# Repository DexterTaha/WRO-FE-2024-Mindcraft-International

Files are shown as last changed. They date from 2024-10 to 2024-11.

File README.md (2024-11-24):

MINDCRAFT WRO Future Engineers team
====

<p align="center">
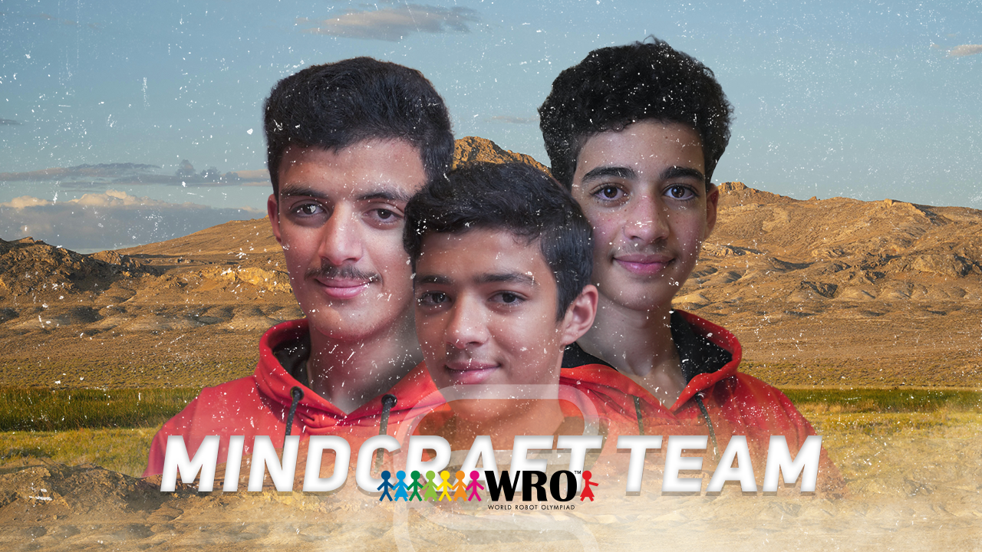
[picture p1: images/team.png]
banner
  
</p>

This repository provides information and knowledge regarding the ongoing progress, evolution, and development of our self-driving robot vehicle, which was created and coded by us, [Salmane Derdeb](https://github.com/salmane-derdeb),  [Taha TAIDI LAAMIRI](https://github.com/DexterTaha) and [Mortada TAIDI LAAMIRI](https://github.com/taidimortada) as participants in the Future Engineers 2024 division of the World Robot Olympiad (WRO).

## World Robot Olympiad (WRO)
<p align="center">
  
</p>

The World Robot Olympiad (WRO) is a prestigious international robotics competition that ignites the imaginations of students worldwide. It challenges participants to showcase their creativity, problem-solving skills, and technical prowess in designing and programming robots for a variety of tasks and challenges.

One of the most dynamic categories within WRO is the Future Engineers category. Here, participants are tasked with developing innovative solutions to real-world problems using robotics and automation. This category serves as a breeding ground for future innovators, encouraging students to think critically and creatively, laying the groundwork for a new generation of engineers and technologists.

This year, the Future Engineers category presents an exciting challenge: creating a self-driving car. This challenge pushes participants to explore the cutting edge of robotics, adding layers of complexity and innovation to an already thrilling competition.

[Watch the challenge explanation video](https://www.youtube.com/watch?v=_J15lf6uhwo&t=2s)

## Content

- `Models`: Contains files for models used by 3D printers, laser cutting machines, and CNC machines to produce the vehicle elements. If not needed, this directory can be removed.
- `docs`: Contains files for models used by 3D printers, laser cutting machines, and CNC machines to produce the vehicle elements. If not needed, this directory can be removed.
- `images`: Contains files for models used by 3D printers, laser cutting machines, and CNC machines to produce the vehicle elements. If not needed, this directory can be removed.
- `other`: Contains additional files that can help understand how to prepare the vehicle for the competition, such as documentation on connecting to a SBC/SBM, uploading files, datasets, hardware specifications, and communication protocols descriptions. If not needed, this directory can be removed.
- `schemes ( source code )`: Contains one or several schematic diagrams (JPEG, PNG, or PDF) illustrating all electromechanical components used in the vehicle, including electronic components and motors, and how they connect to each other.
- `src`: Contains the control software code for all components programmed to participate in the competition.
- `t-photos`: Contains 2 photos of the team, including an official one and a funny photo with all team members.
- `v-photos`: Contains 6 photos of the vehicle, showcasing it from every side as well as from the top and bottom.
- `videos`: Contains a `video.md` file with a link to a video demonstrating the vehicle's driving capabilities.

# WRO Future Engineers Competition

| **1.Mobility Management**             |
|:---------------------------------------|
| Mobility management discussion should cover how the vehicle movements are managed. What motors are selected, how they are selected and implemented. A brief discussion regarding the vehicle chassis design /selection can be provided as well as the mounting of all components to the vehicle chassis/structure. The discussion may include engineering principles such as speed, torque, power etc. usage. Building or assembly instructions can be provided together with 3D CAD files to 3D print parts.|
| [Robot Parts & Design](https://github.com/DexterTaha/WRO-FE-2024-Mindcraft-International/tree/2bbf1b3f514550d7e91d4fa6e24702a49f4da584/Models)      |
| [Power System](https://github.com/DexterTaha/WRO-FE-2024-Mindcraft-International/tree/ba104a2bcaaa4348022537fc64ced3bace19f17f/other/Power%20System) |
| [Sensing Units](https://github.com/DexterTaha/WRO-FE-2024-Mindcraft-International/tree/ba104a2bcaaa4348022537fc64ced3bace19f17f/other/Sensing%20Units) |
| [Steering System](https://github.com/DexterTaha/WRO-FE-2024-Mindcraft-International/tree/ba104a2bcaaa4348022537fc64ced3bace19f17f/other/Steering%20System) |

---

| **2.Power and Sense Management**        |
|:---------------------------------------|
|Power and Sense management discussion should cover the power source for the vehicle as well as the sensors required to provide the vehicle with information to negotiate the different challenges. The discussion can include the reasons for selecting various sensors and how they are being used on the vehicle together with power consumption. The discussion could include a wiring diagram with BOM for the vehicle that includes all aspects of professional wiring diagrams.|
| [Bill of Materials (BOM)](https://github.com/DexterTaha/WRO-FE-2024-Mindcraft-International/tree/2bbf1b3f514550d7e91d4fa6e24702a49f4da584/other/BOM(Bill%20of%20Materials))            |
| [Schematics](https://github.com/DexterTaha/WRO-FE-2024-Mindcraft-International/tree/2bbf1b3f514550d7e91d4fa6e24702a49f4da584/schemes)                   |

---

| **3.Obstacle Management**               |
|:---------------------------------------|
|Obstacle management discussion should include the strategy for the vehicle to negotiate the obstacle course for all the challenges. This could include flow diagrams, pseudo code and source code with detailed comments.|
| [Strategy](https://github.com/DexterTaha/WRO-FE-2024-Mindcraft-International/tree/2bbf1b3f514550d7e91d4fa6e24702a49f4da584/other/Strategy) |
| [Arduino Functions](https://github.com/DexterTaha/WRO-FE-2024-Mindcraft-International/tree/2bbf1b3f514550d7e91d4fa6e24702a49f4da584/src%20(%20source%20code%20)/Arduino%20Functions) |
| [Open challenge](https://github.com/DexterTaha/WRO-FE-2024-Mindcraft-International/tree/2bbf1b3f514550d7e91d4fa6e24702a49f4da584/src%20(%20source%20code%20)/Open%20Challenge) |
| [Dashboard Visualisation](https://github.com/DexterTaha/WRO-FE-2024-Mindcraft-International/tree/2bbf1b3f514550d7e91d4fa6e24702a49f4da584/src%20(%20source%20code%20)/Dashboard)|
| [Map randomizer & score calculator](https://dextertaha.github.io/WRO-FE-2024-Mindcraft-International/)|

---

| **4.Pictures – Team and Vehicle**       |
|:---------------------------------------|
| Pictures of the team and robot must be provided. The pictures of the robot must cover all sides of the robot, must be clear, in focus and show aspects of the mobility, power and sense, and obstacle management. Reference in the discussion sections 1, 2 and 3 can be made to these pictures. Team photo is necessary for judges to relate and identify the team during the local and international competitions. |
| [Vehicle Photos](https://github.com/DexterTaha/WRO-FE-2024-Mindcraft-International/tree/2bbf1b3f514550d7e91d4fa6e24702a49f4da584/v-photos)           |
| [Team Members & Pictures](https://github.com/DexterTaha/WRO-FE-2024-Mindcraft-International/tree/2bbf1b3f514550d7e91d4fa6e24702a49f4da584/t-photos)             |

---

| **5.Performance Videos**                |
|:---------------------------------------|
| The performance videos must demonstrate the performance of the vehicle from start to finish for each challenge. The videos could include an overlay of commentary, titles or animations. The video could also include aspects of section 1, 2 or 3. |
| [Demonstration Videos](https://github.com/DexterTaha/WRO-FE-2024-Mindcraft-International/tree/2bbf1b3f514550d7e91d4fa6e24702a49f4da584/videos) |
| [Youtube Channel](https://www.youtube.com/@MindcraftWRO-kw8vp)|

---

| **6.GitHub Utilization**                |
|:---------------------------------------|
| Git and GitHub are available for opensource project management and file version control. As part of the design and development process, teams must use this platform to document their progress, coding development and share files. Judging the platform will include how complete the information provided is, how information is structured and how often commits were done. Teams can use this platform to provide additional information on their engineering design and coding of their vehicle as well.|
| [Repository Link](https://github.com/DexterTaha/WRO-FE-2024-Mindcraft-International) |

---

| **7.Engineering Factor**                |
|:---------------------------------------|
| Own Design and manufacturing of vehicle and components, with off the shelf electrical components, such as motors and sensors. |
| [Design Description](https://github.com/DexterTaha/WRO-FE-2024-Mindcraft-International/tree/2e0510bb5057f1936545975d4327144dd42a107b/Models/%20Parts) |

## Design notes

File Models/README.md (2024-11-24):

# WRO Future Engineers Robot - Models

This section covers the **CAD modeling and manufacturing process** behind the development of our robot for the **WRO Future Engineers competition**, explaining our design tools, choices, and manufacturing techniques. The following highlights the key decisions in our process and why they benefit the project.

## Table of Contents

1. [Design Considerations Before CAD Modeling](#design-considerations-before-cad-modeling)
   - [Key Requirements](#key-requirements)
   - [Study and Planning](#study-and-planning)
2. [Initial Robot Design and Iterations](#initial-robot-design-and-iterations)
   - [National Competition: LEGO Robot](#national-competition-lego-robot)
   - [First Version: Oversized DIY Robot](#first-version-oversized-diy-robot)
   - [Second Version: Lack of Differential System](#second-version-lack-of-differential-system)
   - [Third Version: Final Optimized Robot](#third-version-final-optimized-robot)
3. [3D CAD Modeling - Onshape](#3d-cad-modeling---onshape)
   - [Why We Chose Onshape](#why-we-chose-onshape)
   - [Video of Onshape Demonstration](#video-of-onshape-demonstration)
   - [Screenshots of Our Robot 3D Model in Onshape](#screenshots-of-our-robot-3d-model-in-onshape)
   - [Other CAD Options Considered](#other-cad-options-considered)
   - [Onshape Advantages](#onshape-advantages)
   - [Learning Onshape](#learning-onshape)
4. [3D Printing](#3d-printing)
   - [Why We Chose 3D Printing](#why-we-chose-3d-printing)
   - [Printer of Choice: Creality K1 Max](#printer-of-choice-creality-k1-max)
   - [3D Printed Robot Parts](#3d-printed-robot-parts)
   - [Video of Printing a Part](#video-of-printing-a-part)
   - [Why We Didn't Choose Laser Cutting or CNC Engraving](#why-we-didnt-choose-laser-cutting-or-cnc-engraving)
5. [Robot](#robot)
   - [Robot Assembly](#robot-assembly)
   - [Power System](#power-system)
   - [Steering System](#steering-system)
6. [Robot Parts Details](#robot-parts-details)
7. [Conclusion](#conclusion)

---

## Design Considerations Before CAD Modeling

Before we began the CAD modeling process, we conducted a thorough study to establish the key requirements and considerations for our robot design. Our primary goal was to create a robot that is efficient, reliable, and optimized for the competition's challenges. The following points outline the main factors we considered:

### Key Requirements

- **Compact Size**: Our strategy required the robot to be smaller than a **20cm cube** to navigate efficiently through the competition environment.
- **Turning Radius**: The robot must be able to turn within an outside circle of maximum **40cm**, enabling it to maneuver in tight spaces.
- **Stability**: A **low center of gravity** was essential to ensure the robot's stability during movement and operations.
- **Weight Distribution**: **Equal weight distribution** across the robot prevents tipping and improves handling.
- **Traction**: High **friction on traction wheels** was necessary to prevent slipping and to provide better control.
- **Assembly Method**: All robot parts should be assembled using **screws**, **nuts**, and **zip ties**—**no glue**—to allow for easy modifications and repairs.
- **Ease of Modification**: The robot should be **sturdy yet easy to modify** and improve as needed.
- **Lightweight Design**: Keeping the robot as **lightweight as possible** enhances speed and reduces energy consumption.
- **Differential System**: Incorporating a **differential system** allows the robot to turn easily and smoothly.
- **Battery Safety**: The battery should be placed in a **safe location** to avoid damage from bumps or accidents, and to prevent hazards if the battery fails.
- **Component Safety**: Critical components should be **protected from potential battery issues**, such as leaks or explosions.
- **Ease of Reassembly**: The robot should be **easy to rebuild**, with parts designed to assemble in only **one way** to minimize errors.
- **Availability of Parts**: All parts should be **commonly available** in most markets to allow other teams to rebuild or service the robot if needed.

### Study and Planning

We meticulously planned the robot's design to meet these requirements. By prioritizing a compact and stable structure, we ensured that the robot could navigate the competition course effectively. The decision to use common assembly methods and readily available parts not only facilitated our building process but also made our design accessible to others.

## Initial Robot Design and Iterations

Our journey began with initial prototypes and several iterations to refine our robot design. Throughout this process, we learned valuable lessons that informed our final design.

### National Competition: LEGO Robot

We participated in the **national competition** with a robot constructed using **LEGO components** due to their ease of use and availability. However, this version had several issues:

- **Size and Speed Issues**: The robot was **too big and slow**, exceeding the size limitations we had set and lacking the required speed.
- **Obstacle Challenges**: We couldn't manage to successfully complete the **obstacle challenge and parking**, which are critical parts of the competition.
- **Structural Limitations**: LEGO components did not provide the **sturdiness** and customization required for the competition's demands.

*Image of LEGO Robot Used in National Competition:*

[LEGO Robot](https://github-production-user-asset-6210df.s3.amazonaws.com/130682580/337490248-3f184c4a-aa2b-491f-9ec5-0fe420d42f31.gif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)

### First Version: Oversized DIY Robot

After qualifying for the international stage, we decided to build a **100% DIY robot**, making all the mechanics and body ourselves while purchasing only the electronics. Our first DIY version had the following issues:

- **Size Issue**: The robot was **still too big**, not meeting our compact size requirement of fitting within a 20cm cube.
- **Weight Problems**: The larger size contributed to increased weight, affecting speed and maneuverability.
- **Inefficient Design**: The oversized structure made it difficult to navigate the course effectively.

*Link of First DIY Robot Version:*

[First DIY Robot](https://cad.onshape.com/documents/08595aa7e5b1cdab597252fc/w/cfc7e06246a86472db038f97/e/671ce5308fe71051d562260c)

### Second Version: Lack of Differential System

In the second iteration of our DIY robot, we attempted to reduce the size and weight but encountered new challenges:

- **No Differential System**: The robot **lacked a differential system**, making turning difficult and inefficient.
- **Poor Maneuverability**: The robot would **drift a lot** and took **150cm** to complete a full turn, which is unacceptable for tight course navigation.
- **Inefficient Turning Radius**: The large turning radius prevented the robot from handling obstacles and precise movements required in the competition.

*Link of Second DIY Robot Version:*

[Second DIY Robot](https://cad.onshape.com/documents/fbbf77d5a7d51852563af36e/w/afa3b15c16b20a57b3f67b6c/e/98887fbf0f458e0817d24d8b)

### Third Version: Final Optimized Robot

For the third version, we made significant changes to address the previous shortcomings:

- **Incorporation of Differential System**: We added a **differential system** to allow smooth and efficient turning.
- **Hardware Upgrade**: We switched from using the **NVIDIA Jetson Nano** to the **Raspberry Pi 4 Model B**, which provided:

  - **Improved Compatibility**: Better compatibility with our control systems and peripherals.
  - **Weight Reduction**: The Raspberry Pi is **lighter**, contributing to our goal of a lightweight robot.
  - **Energy Efficiency**: Lower power consumption helped manage the robot's energy requirements.

- **Optimized Design**: The robot now fits within the **20cm cube** constraint, has a **low center of gravity**, and features **equal weight distribution**.
- **Enhanced Maneuverability**: With the differential system, the robot can turn efficiently within the required **40cm outside circle**.
- **Sturdy and Modular Assembly**: All parts are assembled using screws, nuts, and zip ties—no glue—making the robot sturdy yet easy to modify and improve.
- **Safety Features**: The battery is placed in a safe location to avoid damage from bumps or accidents, and critical components are protected from potential battery issues.

*Link of Third DIY Robot Version:*

[Third DIY Robot](https://cad.onshape.com/documents/1c6f1405e84d0c390333223c/w/c90b719cdc670bdbfb16a84e/e/7f48b1d9bd685347e4768d04)

This final version solved all the problems encountered in previous iterations, resulting in a robot that is compact, efficient, and competition-ready.

## 3D CAD Modeling - Onshape

To design and develop the robot, we used **Onshape**, a cloud-based CAD tool that allows for efficient collaboration and design flexibility. We had various options for CAD software, such as **Fusion 360** and **CATIA**, but we ultimately chose Onshape for several reasons:

### Why We Chose Onshape

- **Cloud-Based**: Onshape operates entirely in the cloud, allowing our team to collaborate from any location. This was essential since team members were working from different places.
- **Collaborative Design**: Multiple team members can work on the same design simultaneously, ensuring faster iterations and feedback loops.
- **Free for Educational Use**: Being students representing Morocco, Onshape’s free educational plan provided us with full access to powerful design tools without extra costs.
- **No Hardware Constraints**: Onshape runs in a web browser, meaning we didn’t need high-end computers or complex software installations. This allowed everyone on the team to contribute regardless of their hardware limitations.

You can learn more about Onshape here: [Onshape Website](https://www.onshape.com/)

### Video of Onshape Demonstration

Watch the video (https://github.com/user-attachments/assets/29b17698-be3b-4aab-8515-d6c245b77802)

### Screenshots of Our Robot 3D Model in Onshape

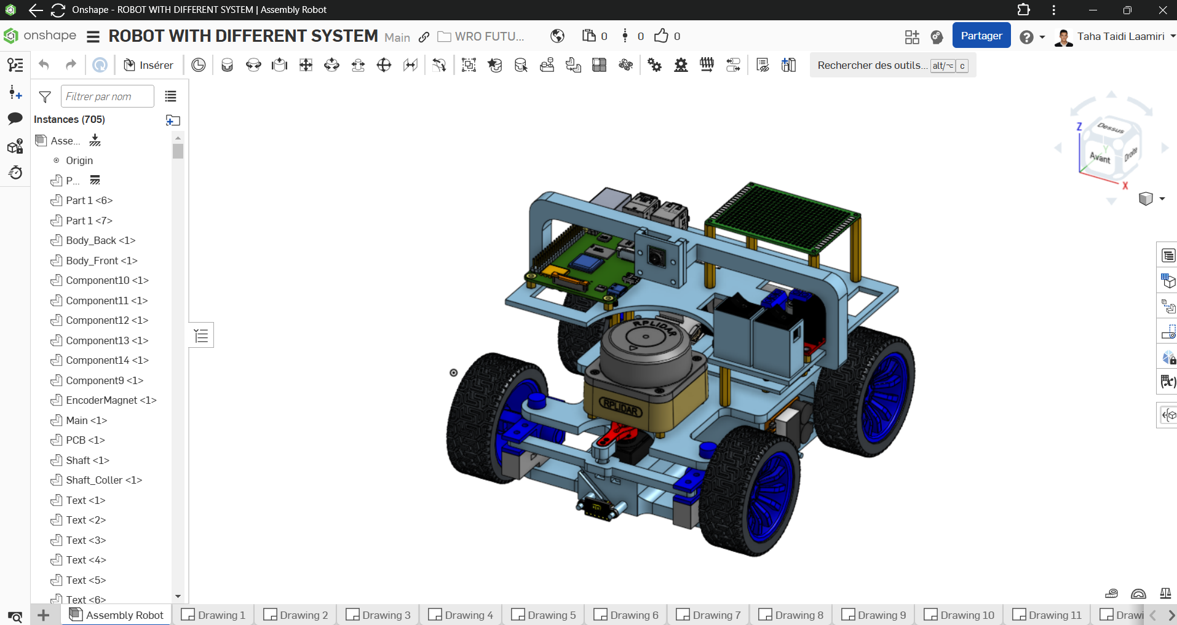
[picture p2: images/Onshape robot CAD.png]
Robot Chassis Design


### Other CAD Options Considered

- **Fusion 360**: Hybrid cloud solution, limited collaboration, and high costs.
- **CATIA**: Too complex and expensive for our needs.

### Onshape Advantages

- **Real-Time Collaboration**: Multiple people can work on the design at the same time, accelerating the design process.
- **Accessible Anywhere**: Since it’s cloud-based, we could work on designs from any device with an internet connection.
- **Powerful CAD Tools**: Despite being browser-based, Onshape provides all the advanced CAD features we needed to design complex mechanical components for our robot.
- **Version Control**: We could easily track changes, revert to previous versions, and work on multiple iterations without losing progress.

### Learning Onshape

We learned how to use Onshape through resources from the official Onshape website and a helpful playlist on YouTube.

- [Onshape Official Website](https://www.onshape.com/learn)
- [Onshape YouTube Playlist](https://youtube.com/playlist?list=PL4FdDkwWXT9p3IaT11JjJcnwnFWiHJuco&si=v0Z2kmiZvLGKHOFY)

## 3D Printing

Once our designs were finalized in Onshape, we needed to choose a manufacturing method. We considered several techniques like **laser cutting**, **CNC engraving**, and **3D printing**, but we ultimately decided to use **3D printing** due to its flexibility and ability to produce complex parts for our robot.

### Why We Chose 3D Printing

- **Complex Geometries**: 3D printing allowed us to create complex and custom geometries that are difficult to achieve with laser cutting or CNC engraving.
- **Rapid Prototyping**: We could quickly print and test various parts, allowing us to make fast iterations on our robot design.
- **Cost-Effective**: 3D printing is often more affordable for one-off parts or prototypes compared to CNC engraving or laser cutting, which require more setup and material waste.
- **Less Material Waste**: 3D printing only uses the material needed for the part, reducing waste and lowering costs.

### Printer of Choice: Creality K1 Max

We selected the **Creality K1 Max** 3D printer for manufacturing our robot parts. This printer has several key advantages:

- **Large Build Volume**: The K1 Max provides a large build area, allowing us to print large components of the robot in a single go without having to divide them into smaller parts.
- **High Speed**: With fast print speeds, we were able to print our parts in a short amount of time, keeping up with the rapid pace of our project.
- **Precision**: The Creality K1 Max delivers high accuracy and detail in its prints, ensuring that our robot's mechanical parts fit together perfectly.
- **Ease of Use**: The printer is easy to set up and use, even for students, making it an ideal choice for quick prototyping.

Learn more about the Creality K1 Max here: [Creality K1 Max Printer](https://www.creality.com/products/creality-k1-max-3d-printer?spm=..404.header_1.1)

### 3D Printed Robot Parts

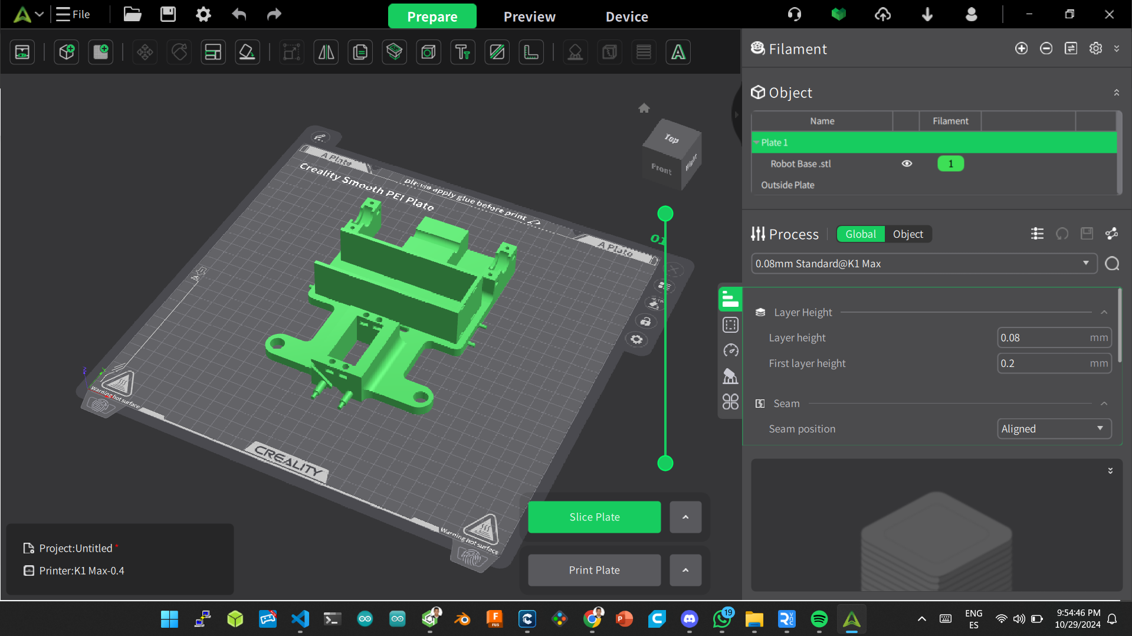
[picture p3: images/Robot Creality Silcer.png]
3D Printed Robot Parts


### Video of Printing a Part

Watch the video (https://github.com/user-attachments/assets/a05f5144-69ca-4180-a867-5e9cf91d8875)

*This video was made by us while printing the robot base of our robot.*

### Why We Didn't Choose Laser Cutting or CNC Engraving

- **Laser Cutting**: While laser cutting is great for creating flat, 2D parts, it is limited in producing complex 3D shapes and detailed mechanical components.
- **CNC Engraving**: CNC is excellent for metal and wood parts but involves more setup time and higher costs, especially for custom parts. It also generates more material waste, making it less ideal for our project, which requires many iterations.

### Advantages of 3D Printing

- **Customization**: We can easily make modifications to the design and print new parts within hours.
- **Quick Turnaround**: 3D printing enabled us to quickly prototype, test, and refine parts, significantly reducing development time.
- **Sustainable**: With 3D printing, there’s less waste of materials, aligning with our goal of sustainability for this project.

## Robot

### Robot Assembly

| | Robot |
|---|---|
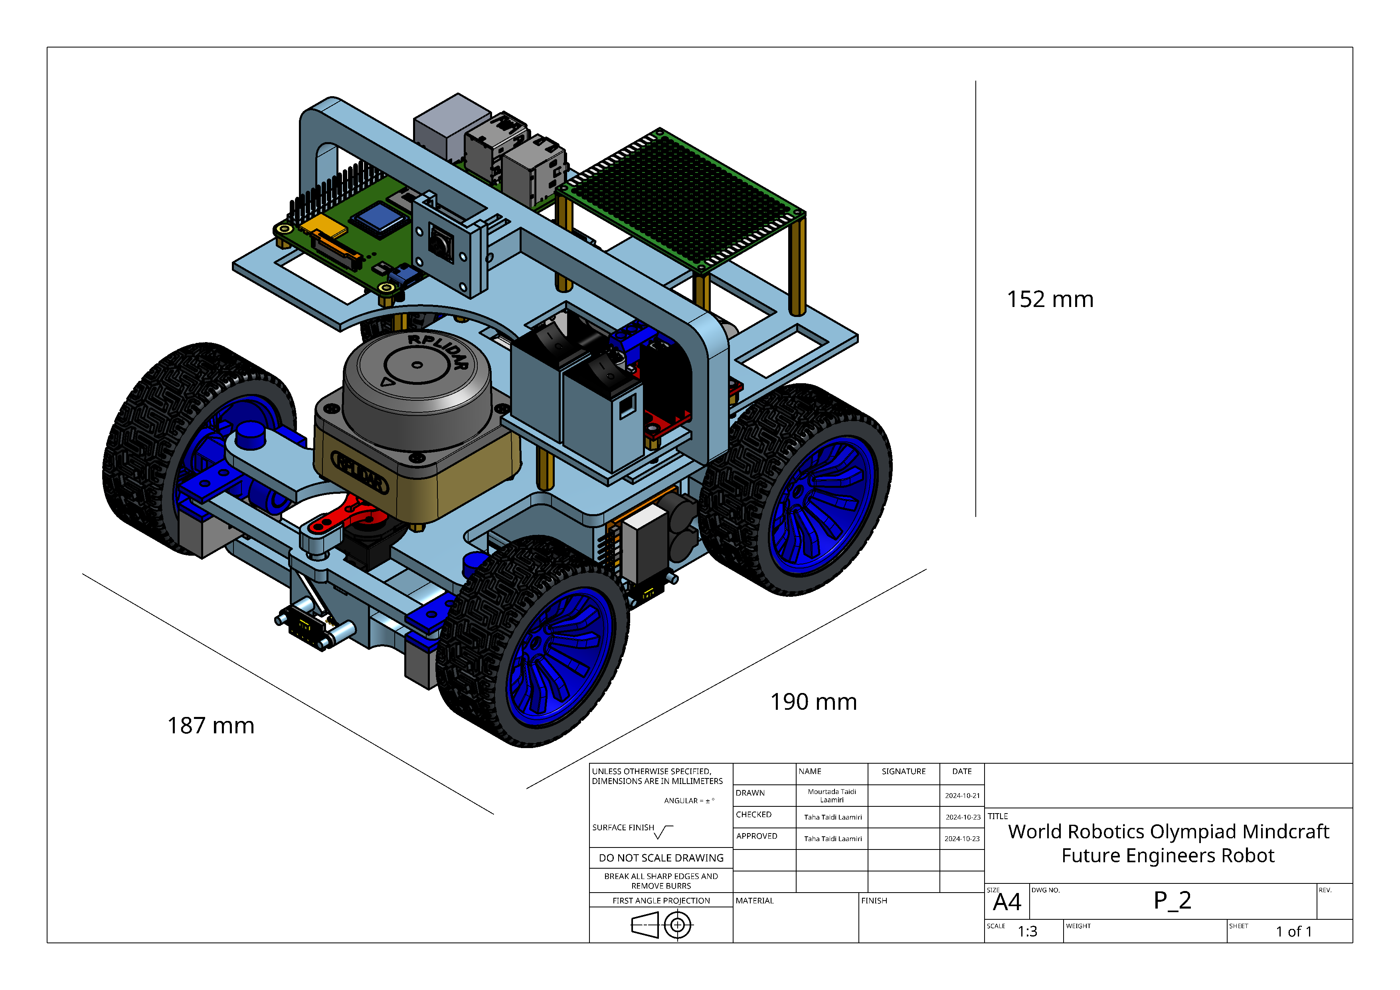
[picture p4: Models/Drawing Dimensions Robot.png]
Robot Dimensions
| Robot Dimensions  |  |
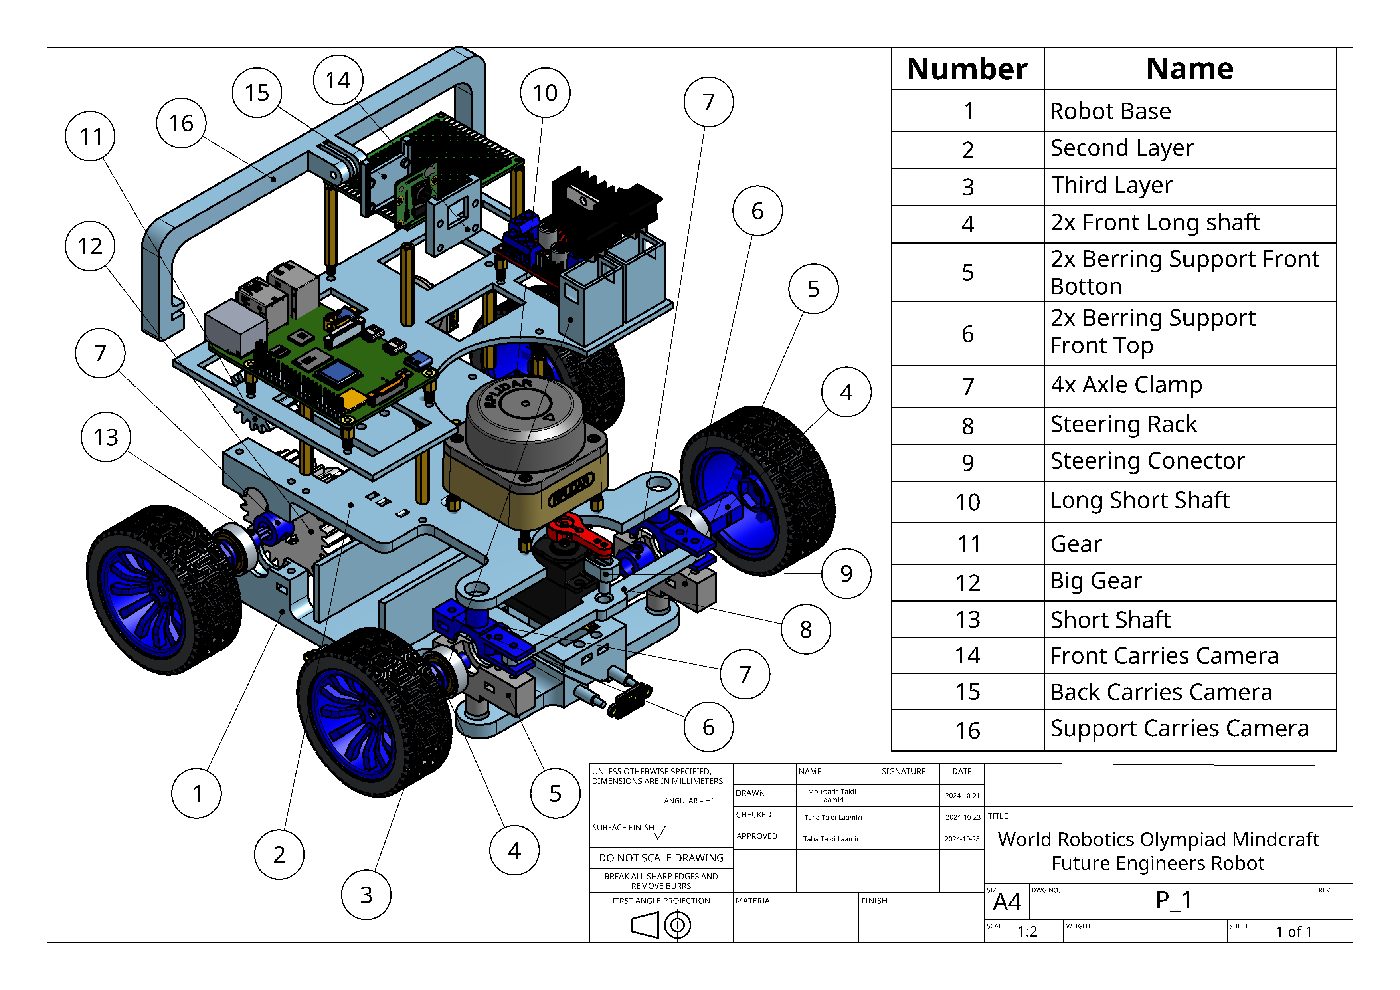
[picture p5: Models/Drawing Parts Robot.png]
Robot Assembly
| Robot Assembly |  |
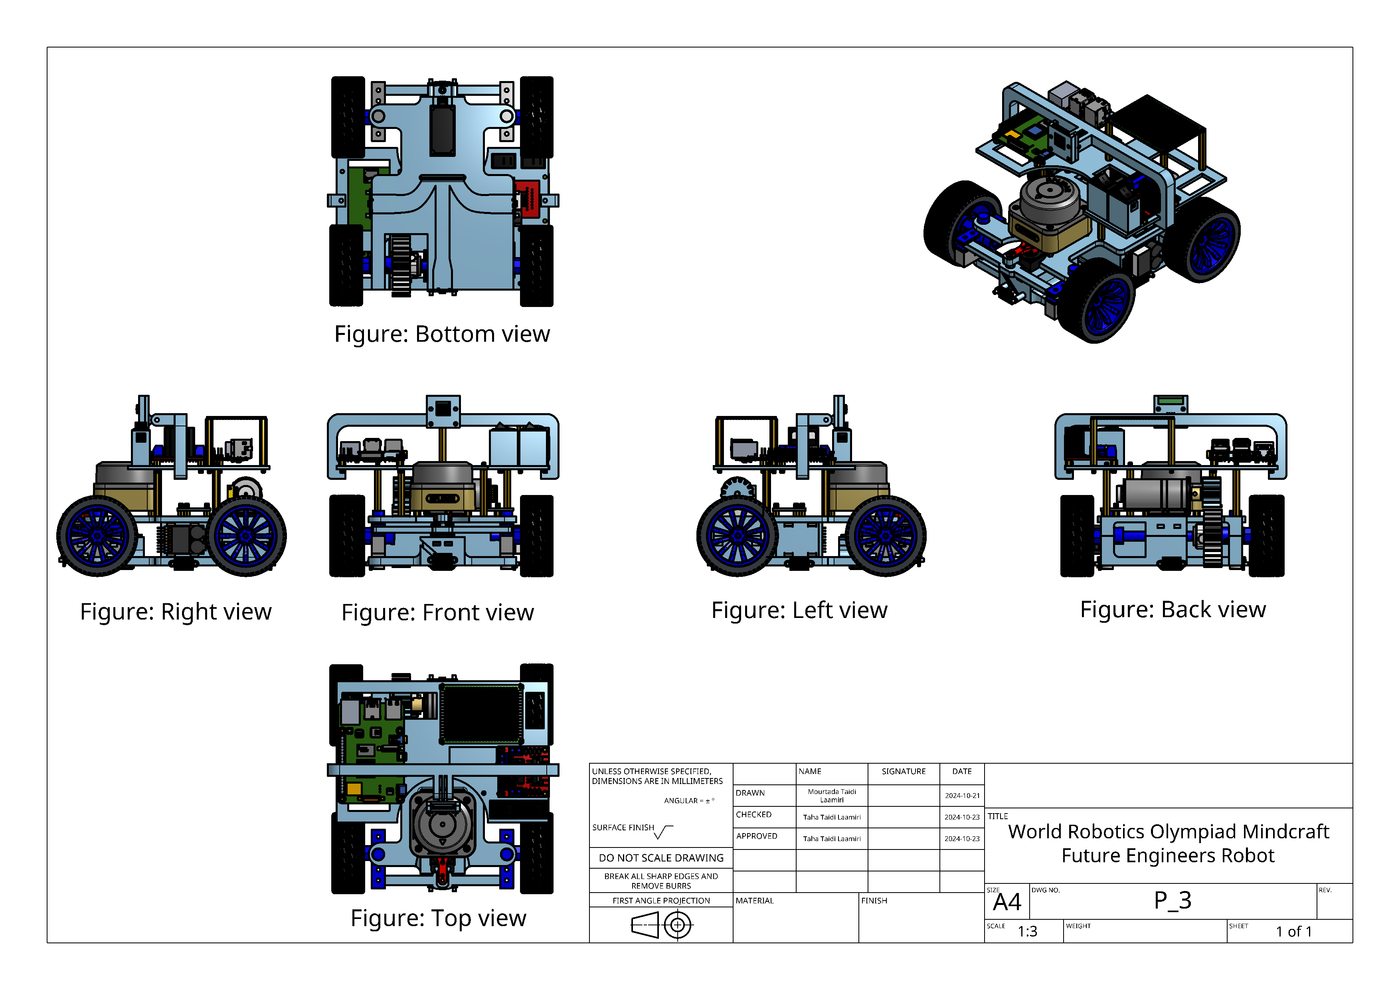
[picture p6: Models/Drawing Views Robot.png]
Robot View
| Robot View |  |

### Power System

| | Power System |
|---|---|
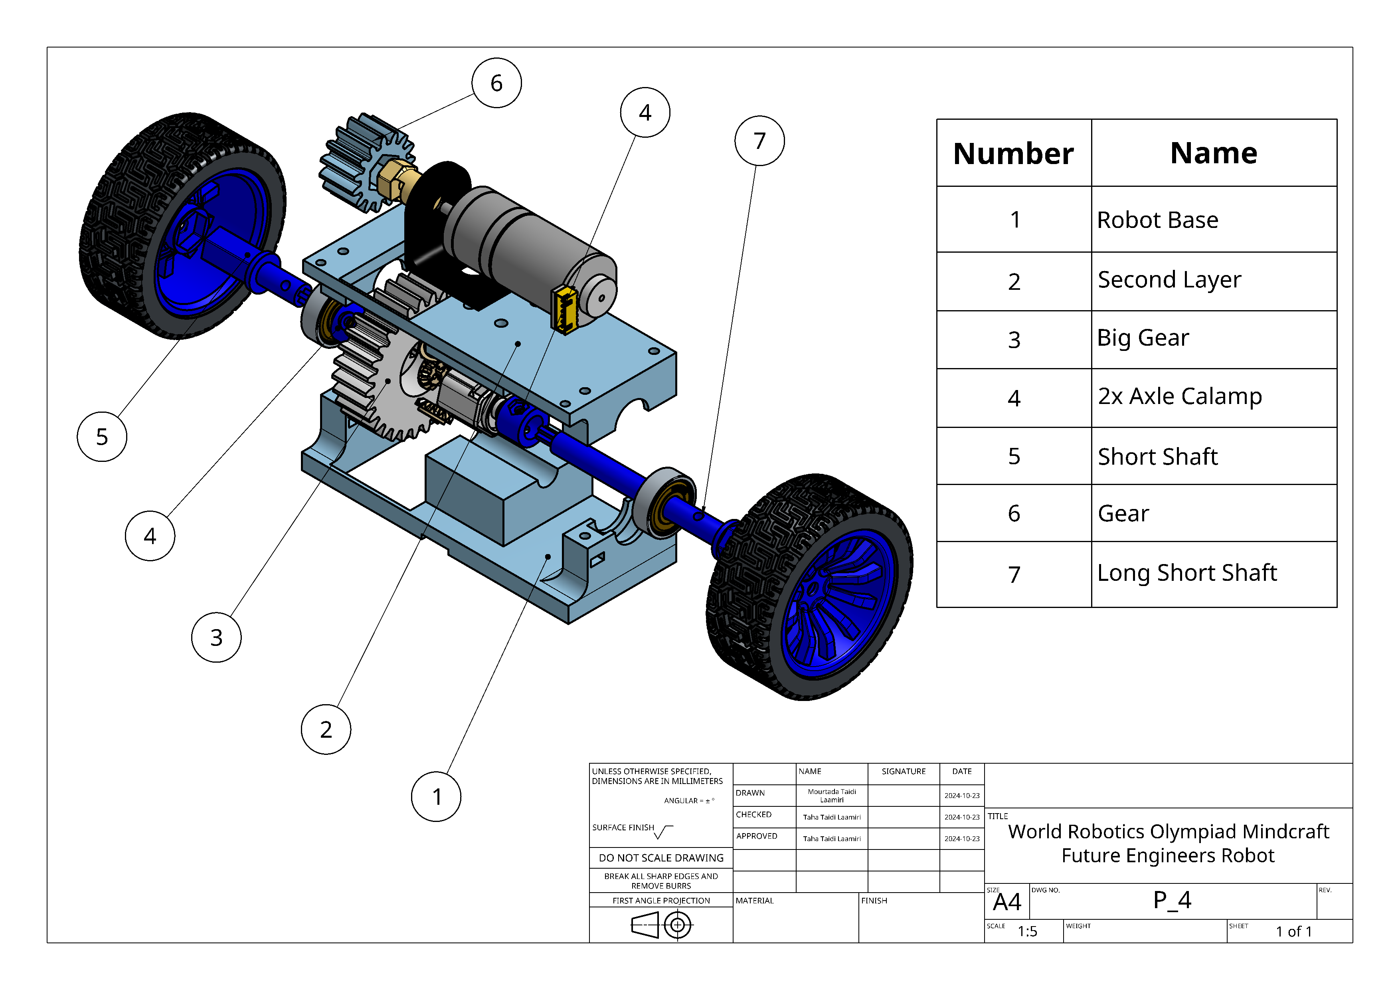
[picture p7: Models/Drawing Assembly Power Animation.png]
Power System Assembly
| Power System Assembly |  |
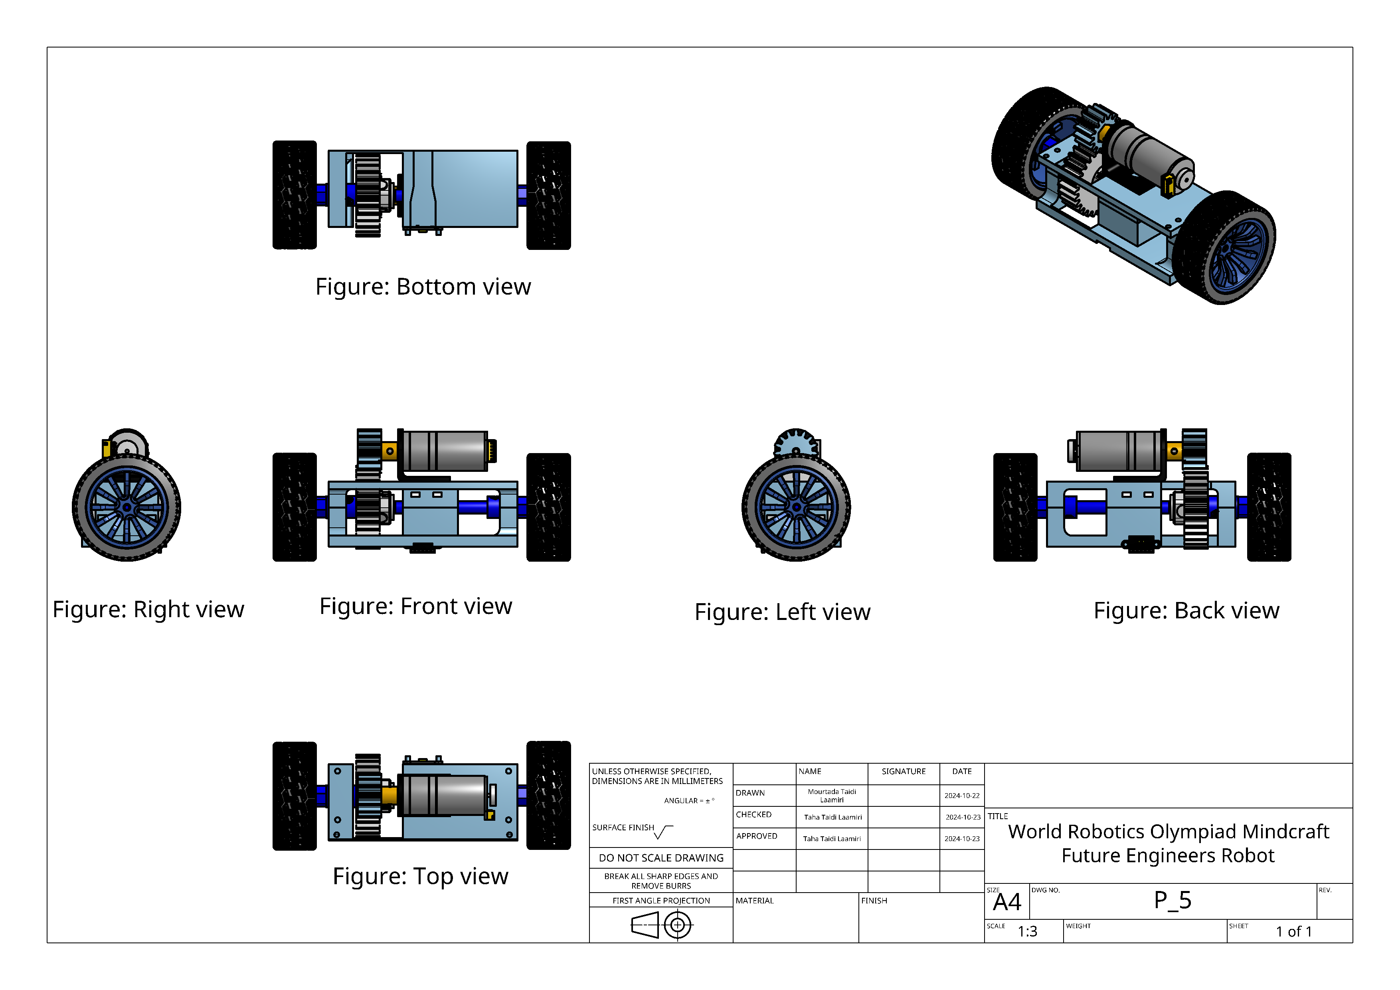
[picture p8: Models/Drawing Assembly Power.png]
Power System View
| Power System View |  |

### Steering System

| | Steering System |
|---|---|
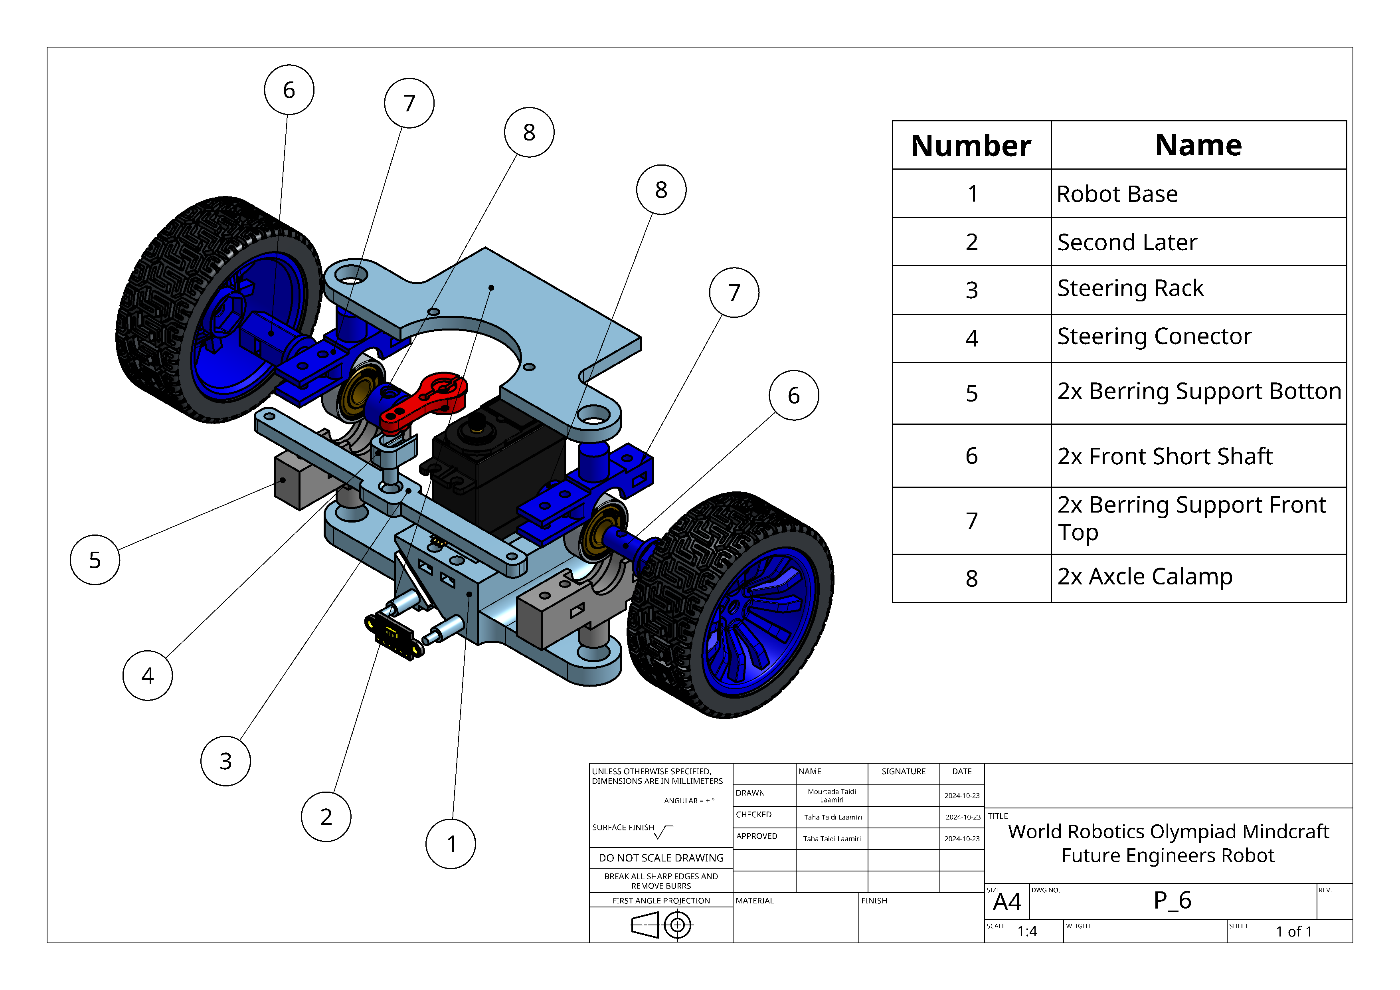
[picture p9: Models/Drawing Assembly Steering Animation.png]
Steering System Assembly
| Steering System Assembly |  |
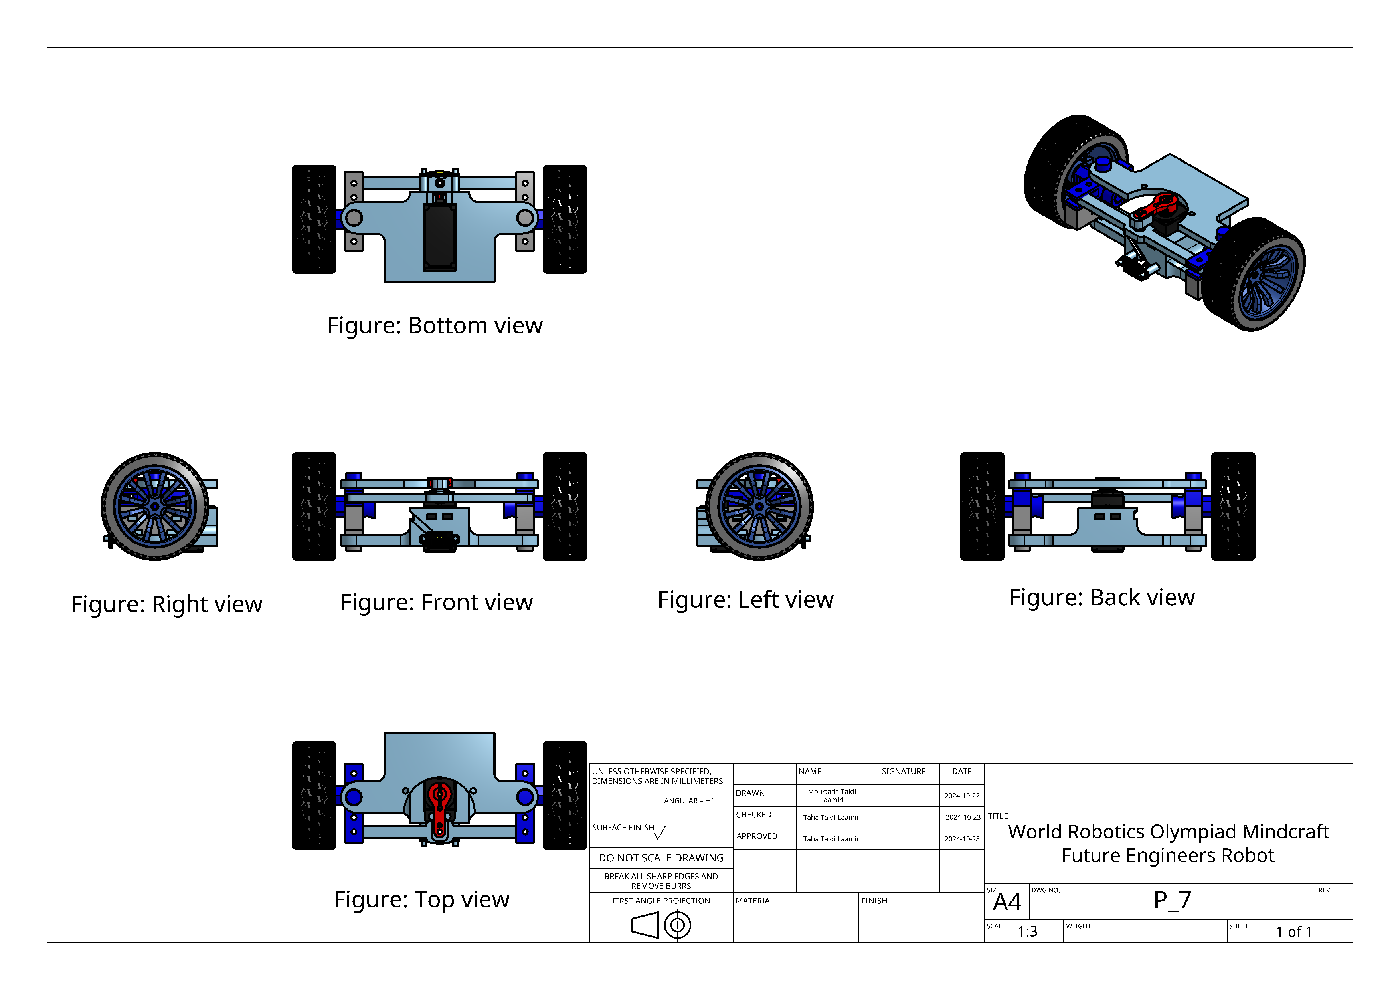
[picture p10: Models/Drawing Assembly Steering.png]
Steering System View
| Steering System View |  |

## Robot Parts Details

| Part Name | Image | 3D File Link |
|---|---|---|
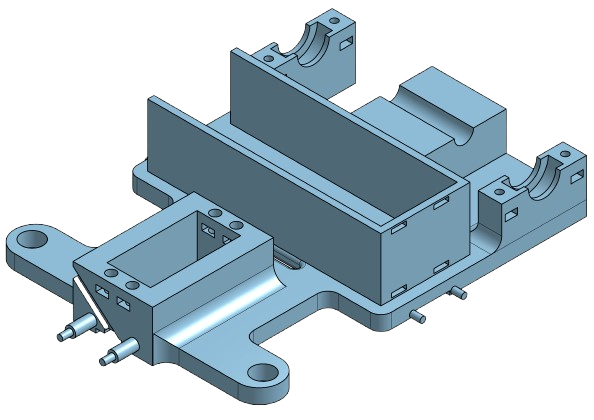
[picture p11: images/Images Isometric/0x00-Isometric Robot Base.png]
Robot Base
| 0x00- Robot Base |  | [Part Details](https://github.com/DexterTaha/WRO-FE-2024-Mindcraft-International/tree/main/Models/%20Parts/0x00-Robot%20Base) |
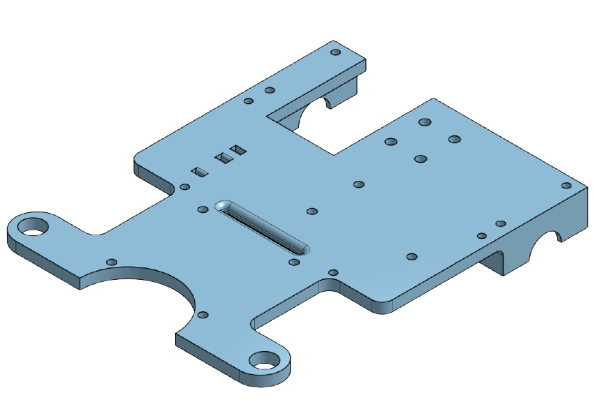
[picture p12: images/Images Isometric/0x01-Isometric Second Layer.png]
Second Layer
| 0x01- Second Layer |  | [Part Details](https://github.com/DexterTaha/WRO-FE-2024-Mindcraft-International/tree/main/Models/%20Parts/0x01-Second%20Layer) |
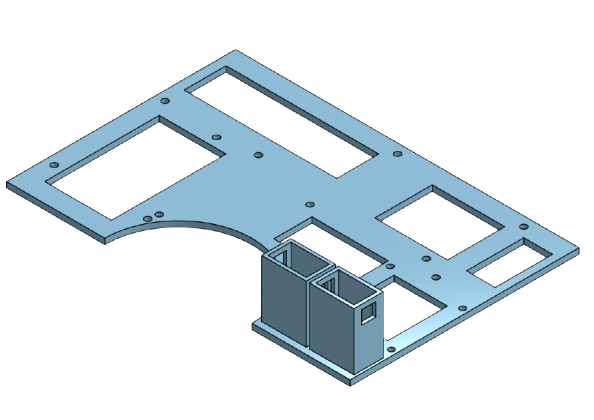
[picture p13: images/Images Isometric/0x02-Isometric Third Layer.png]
Third Layer
| 0x02- Third Layer |  | [Part Details](https://github.com/DexterTaha/WRO-FE-2024-Mindcraft-International/tree/main/Models/%20Parts/0x02-Third%20Layer) |
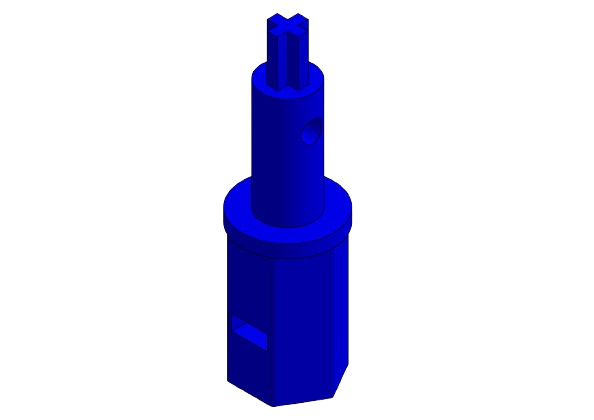
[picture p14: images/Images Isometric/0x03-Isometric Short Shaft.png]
Short Shaft
| 0x03- Short Shaft |  | [Part Details](https://github.com/DexterTaha/WRO-FE-2024-Mindcraft-International/tree/main/Models/%20Parts/0x03-Short%20Shaft) |
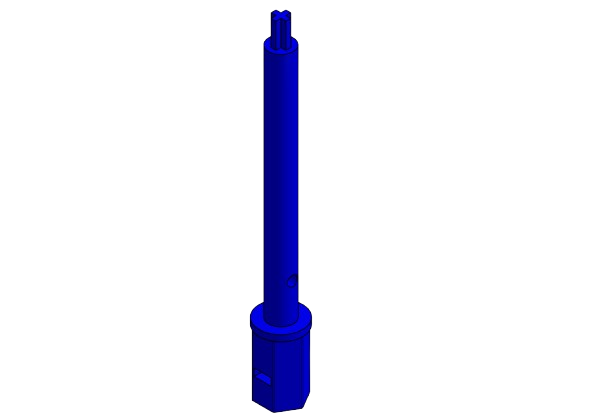
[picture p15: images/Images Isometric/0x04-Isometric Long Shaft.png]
Long Shaft
| 0x04- Long Shaft |  | [Part Details](https://github.com/DexterTaha/WRO-FE-2024-Mindcraft-International/tree/main/Models/%20Parts/0x04-Long%20Shaft) |
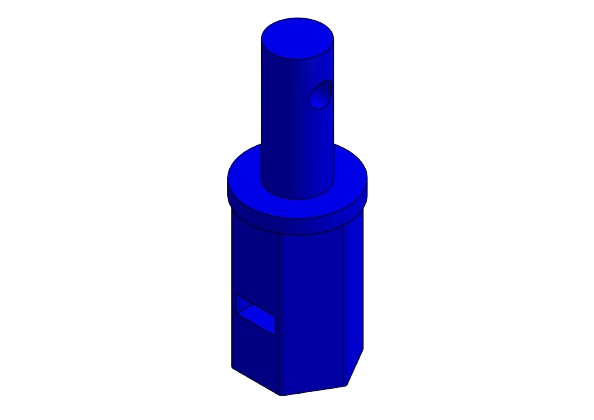
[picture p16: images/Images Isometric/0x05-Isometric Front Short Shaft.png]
Front Short Shaft
| 0x05- Front Short Shaft |  | [Part Details](https://github.com/DexterTaha/WRO-FE-2024-Mindcraft-International/tree/main/Models/%20Parts/0x05-Front%20Short%20Shaft) |
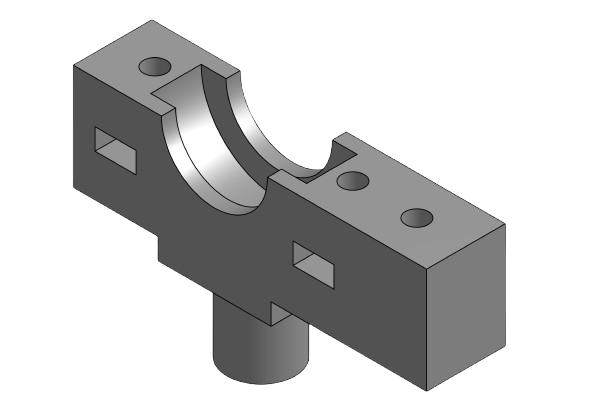
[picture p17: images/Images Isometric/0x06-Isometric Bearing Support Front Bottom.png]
Bearing Support Front Bottom
| 0x06- Bearing Support Front Bottom  |  | [Part Details](https://github.com/DexterTaha/WRO-FE-2024-Mindcraft-International/tree/main/Models/%20Parts/0x06-Berring%20Support%20Front%20Bottom) |
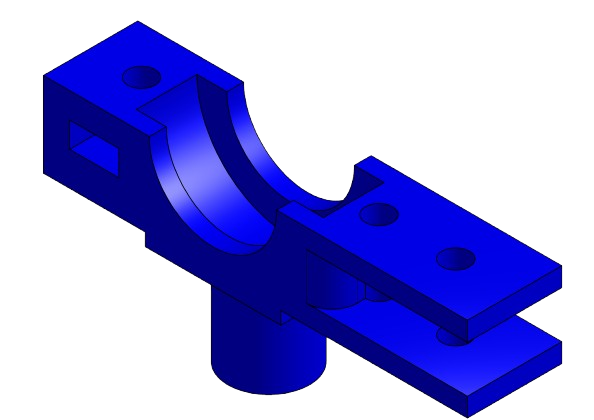
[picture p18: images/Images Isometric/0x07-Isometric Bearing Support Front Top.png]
Bearing Support Front Top
| 0x07- Bearing Support Front Top |  | [Part Details](https://github.com/DexterTaha/WRO-FE-2024-Mindcraft-International/tree/main/Models/%20Parts/0x07-Berring%20Support%20Front%20Top) |
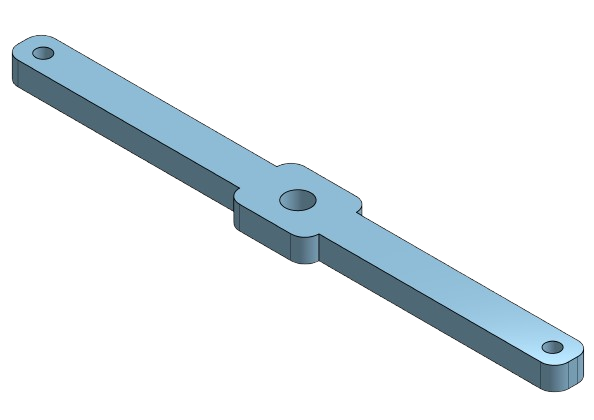
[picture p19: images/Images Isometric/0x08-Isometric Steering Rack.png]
Steering Rack
| 0x08- Steering Rack |  | [Part Details](https://github.com/DexterTaha/WRO-FE-2024-Mindcraft-International/tree/main/Models/%20Parts/0x08-Steering%20Rack) |
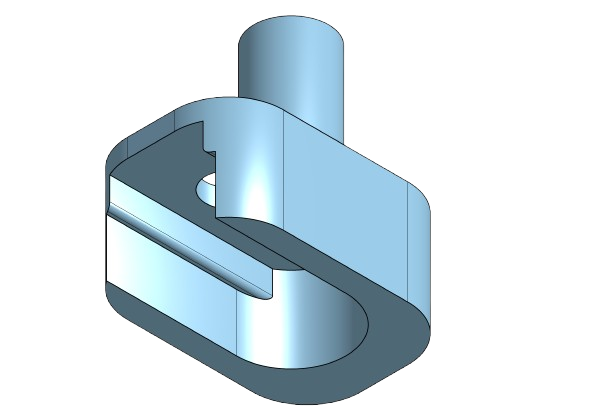
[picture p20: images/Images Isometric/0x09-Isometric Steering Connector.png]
Steering Connector
| 0x09- Steering Connector |  | [Part Details](https://github.com/DexterTaha/WRO-FE-2024-Mindcraft-International/tree/main/Models/%20Parts/0x09-Steering%20Conector) |
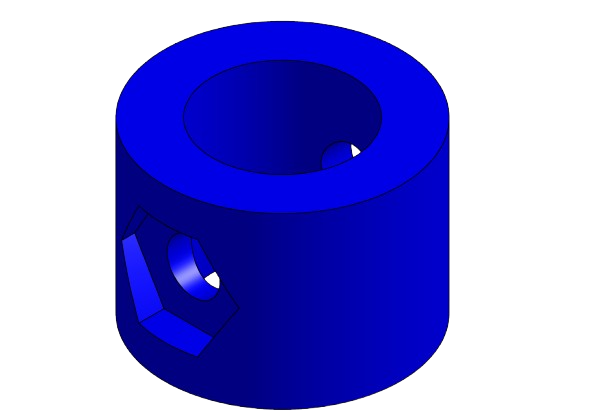
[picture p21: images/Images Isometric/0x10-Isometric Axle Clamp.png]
Axle Clamp
| 0x10- Axle Clamp |  | [Part Details](https://github.com/DexterTaha/WRO-FE-2024-Mindcraft-International/tree/main/Models/%20Parts/0x10-Axle%20Clamp) |
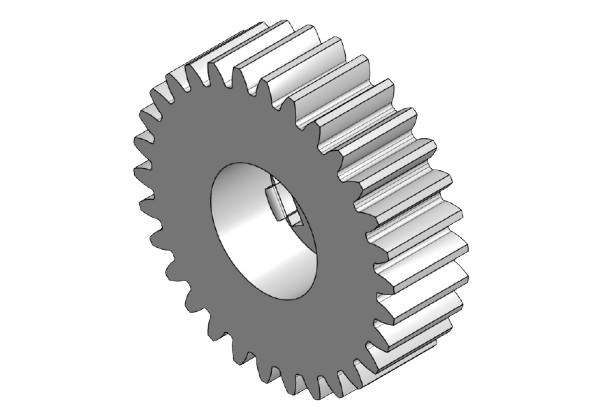
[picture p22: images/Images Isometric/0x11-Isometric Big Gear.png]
Big Gear
| 0x11- Big Gear |  | [Part Details](https://github.com/DexterTaha/WRO-FE-2024-Mindcraft-International/tree/main/Models/%20Parts/0x11-Big%20Gear) |
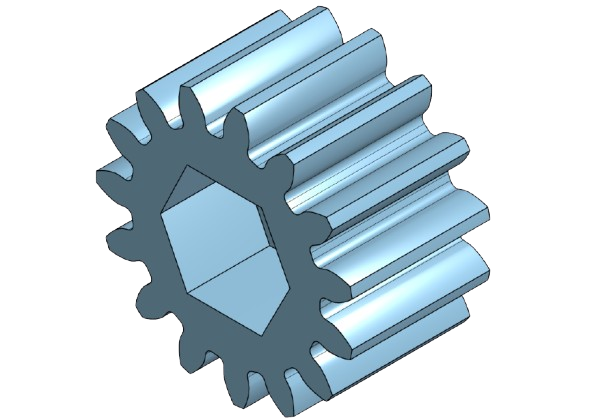
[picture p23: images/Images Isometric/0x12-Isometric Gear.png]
Gear
| 0x12- Gear |  | [Part Details](https://github.com/DexterTaha/WRO-FE-2024-Mindcraft-International/tree/main/Models/%20Parts/0x12-Gear) |
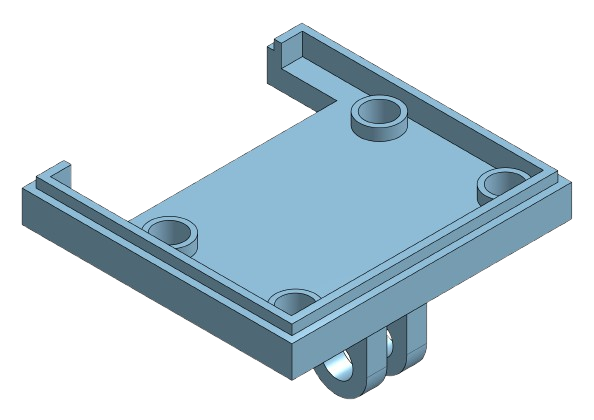
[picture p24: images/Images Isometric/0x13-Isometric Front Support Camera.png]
Front Support Camera
| 0x13- Front Support Camera |  | [Part Details](https://github.com/DexterTaha/WRO-FE-2024-Mindcraft-International/tree/main/Models/%20Parts/0x13-Front%20Support%20Camera) |
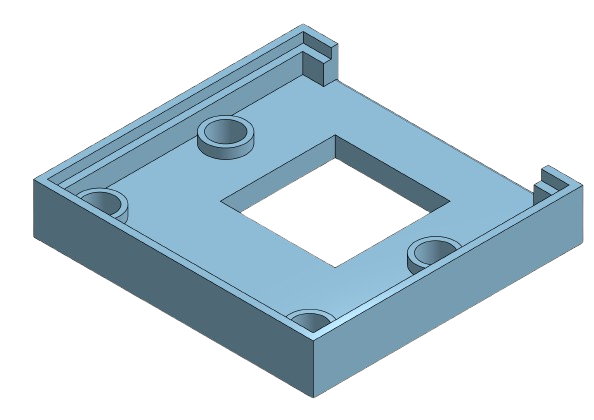
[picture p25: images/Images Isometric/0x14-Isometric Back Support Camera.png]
Back Support Camera
| 0x14- Back Support Camera |  | [Part Details](https://github.com/DexterTaha/WRO-FE-2024-Mindcraft-International/tree/main/Models/%20Parts/0x14-Back%20Support%20Camera) |
| 0x15- Connector Support Camera | Connector Support Camera | [Part Details](https://github.com/DexterTaha/WRO-FE-2024-Mindcraft-International/tree/main/Models/%20Parts/0x15-Conector%20Support%20Camera) |

## Conclusion

For our **WRO Future Engineers robot project**, using **Onshape for CAD modeling** and the **Creality K1 Max for 3D printing** has been a critical part of our design and manufacturing process. These tools allowed us to work collaboratively, iterate quickly, and produce complex parts efficiently, all while staying within the constraints of an educational project.

Thank you for following our journey as we design a cutting-edge robot to represent **Morocco** on the global stage at the **World Robot Olympiad**!

For more information and to follow our progress, check out our [Project Link](https://github.com/DexterTaha/WRO-FE-2024-Mindcraft-International).

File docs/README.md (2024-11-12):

# Future Engineers Map Randomizer and Score Calculator

This project provides an interactive web-based tool for the WRO Future Engineers competition. It combines a map randomizer and a score calculator, allowing participants to simulate various configurations of map elements and assess their robot's performance effectively.

## Table of Contents

- [Features](#features)
- [Getting Started](#getting-started)
  - [Prerequisites](#prerequisites)
  - [Installation](#installation)
- [Creating the Project](#creating-the-project)
  - [Step 1: Setting Up the HTML Structure](#step-1-setting-up-the-html-structure)
  - [Step 2: Styling the Application](#step-2-styling-the-application)
  - [Step 3: Adding JavaScript Logic](#step-3-adding-javascript-logic)
    - [Drawing the Map](#drawing-the-map)
    - [Randomization Logic](#randomization-logic)
    - [Chrono Functionality](#chrono-functionality)
  - [Step 4: Testing the Application](#step-4-testing-the-application)
- [Code Explanation](#code-explanation)
  - [HTML (index.html)](#html-indexhtml)
  - [CSS (style.css)](#css-stylescss)
  - [JavaScript (script.js)](#javascript-scriptjs)
- [Contributing](#contributing)
- [License](#license)

## Features

- **Map Randomizer**: Automatically generates randomized layouts for obstacles and scoring zones.
  
- **Score Calculator**: Quickly calculates scores based on robot interactions with the map elements.

- **Chrono Timer**: Tracks the time taken for the robot to complete the course.

- **Responsive Design**: Built using HTML, CSS, and JavaScript.

- **User-Friendly Interface**: Intuitive design for easy navigation.

## Getting Started

### Prerequisites

To run this project, ensure you have a modern web browser installed, such as:

- Google Chrome
- Mozilla Firefox
- Apple Safari
- Microsoft Edge

### Installation

1. **Download the Repository**: Clone or download the repository to your local machine.
   
   ```bash
   git clone https://github.com/YOUR_USERNAME/WRO-FE-2024-Mindcraft-International.git
   ```

2 - **Open the Project**: Navigate to the project folder and open the `index.html` file in your web browser.

## Creating the Project
### Step 1: Setting Up the HTML Structure
1. **Create an index.html File**: Start by creating an HTML file. This will be the main structure of your web application.
2. **Add Basic HTML Structure**: Inside the `index.html`, include the basic HTML template and a title for your application. Use the following template:

```html
<!DOCTYPE html>
<html lang="en">
<head>
    <meta charset="UTF-8">
    <meta name="viewport" content="width=device-width, initial-scale=1.0">
    <link rel="stylesheet" href="style.css">
    <title>Future Engineers Map Randomizer</title>
</head>
<body>
    <h1>Future Engineers Map Randomizer & Score Calculator</h1>
    <button id="randomizeBtn">Randomize Map</button>

    <h2>Score Calculation</h2>
    <label for="obstaclesAvoided">Obstacles Avoided:</label>
    <input type="number" id="obstaclesAvoided" placeholder="Enter number">
    <label for="pointsFromZones">Points from Scoring Zones:</label>
    <input type="number" id="pointsFromZones" placeholder="Enter points">
    <button id="calculateBtn">Calculate Score</button>

    <h2>Chrono</h2>
    <button id="startChrono">Start Timer</button>
    <button id="stopChrono">Stop Timer</button>
    <p id="chronoDisplay">Time: 0s</p>
    
    <script src="script.js"></script>
</body>
</html>
```

### Step 2: Styling the Application
1. **Create a style.css File**: Create a CSS file in the project folder. This will control the visual appearance of your application.
2. **Add Basic Styles**: Use the following CSS code to provide basic styling for your layout. Customize as needed:

```css
body {
    font-family: Arial, sans-serif;
    text-align: center;
    background-color: #f4f4f4;
}

h1 {
    color: #333;
}

button {
    padding: 10px 15px;
    font-size: 16px;
    margin: 10px;
    cursor: pointer;
}

input {
    padding: 5px;
    margin: 10px;
    width: 50px;
}
```

### Step 3: Adding JavaScript Logic
1. **Create a script.js File**: Create a JavaScript file in your project folder. This will contain the logic for randomization, map drawing, and timer functionality.
2. **Add Event Listeners**: Use the following code to handle user interactions such as randomizing the map, calculating the score, and starting/stopping the timer:

```javascript
let timerInterval;
let seconds = 0;

document.getElementById('randomizeBtn').addEventListener('click', function() {
    const mapDisplay = document.getElementById('mapDisplay');
    const randomMap = generateRandomMap();
    mapDisplay.innerHTML = randomMap;
});

document.getElementById('calculateBtn').addEventListener('click', function() {
    const obstaclesAvoided = document.getElementById('obstaclesAvoided').value;
    const pointsFromZones = document.getElementById('pointsFromZones').value;
    
    const totalScore = calculateScore(obstaclesAvoided, pointsFromZones);
    document.getElementById('result').innerText = `Total Score: ${totalScore}`;
});

document.getElementById('startChrono').addEventListener('click', function() {
    startTimer();
});

document.getElementById('stopChrono').addEventListener('click', function() {
    stopTimer();
});

function generateRandomMap() {
    const obstacles = ['Wall', 'Pit', 'Ramp'];
    const scoringZones = ['Zone A', 'Zone B', 'Zone C'];
    let mapLayout = '';

    for (let i = 0; i < 5; i++) {
        const randomObstacle = obstacles[Math.floor(Math.random() * obstacles.length)];
        const randomZone = scoringZones[Math.floor(Math.random() * scoringZones.length)];
        mapLayout += `<div>${randomObstacle} | ${randomZone}</div>`;
    }

    return mapLayout;
}

function calculateScore(obstacles, points) {
    const pointsForObstacles = 10; // Example points for each obstacle avoided
    return parseInt(points) + (pointsForObstacles * parseInt(obstacles));
}

function startTimer() {
    timerInterval = setInterval(() => {
        seconds++;
        document.getElementById('chronoDisplay').innerText = `Time: ${seconds}s`;
    }, 1000);
}

function stopTimer() {
    clearInterval(timerInterval);
}
```

#### Drawing the Map
In the `generateRandomMap()` function, we create a simple representation of the map by randomly selecting obstacles and scoring zones. The function constructs a string that includes random combinations of these elements, which is then displayed in the `mapDisplay` div.
#### Randomization Logic
The randomization works by selecting a random item from arrays of predefined obstacles and scoring zones. The code uses `Math.random()` and `Math.floor()` to ensure that a valid index is chosen each time a random element is requested.
#### Chrono Functionality
The chrono (timer) functionality is implemented with two main functions: `startTimer()` and `stopTimer()`. The `startTimer()` function sets an interval that increments a seconds counter every second, updating the display accordingly. The `stopTimer()` function clears this interval, effectively stopping the timer.

### Step 4: Testing the Application
1. **Open the Application**: After setting up the files, open `index.html` in your web browser to see the application in action.
2. **Interact with the Application**: Click the "Randomize Map" button to generate a new map layout, enter data in the input fields, calculate the score, and start/stop the timer to ensure everything works as expected.

## Code Explanation
## HTML (index.html)
The HTML file contains the basic structure for the application. It includes buttons for randomizing the map, calculating the score, and managing the timer, as well as input fields for user interaction.
## CSS (style.css)
The CSS file provides styles for the application. You can adjust colors, fonts, and layout to customize the appearance further.
## JavaScript (script.js)
The JavaScript file handles the logic for randomization, score calculation, and timer functionality. It listens for user actions and performs the corresponding operations, updating the displayed results.

## Website Preview
website preview

Access the Website
Explore the interactive tool by visiting the following link:

https://dextertaha.github.io/WRO-FE-2024-Mindcraft-International/

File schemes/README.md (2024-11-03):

Here’s the updated Markdown documentation, clarifying that all components except the camera and LiDAR are connected to the Arduino Nano, while only the camera and LiDAR are connected to the Raspberry Pi.

---

# WRO-FE 2024 Mindcraft International Robot Circuit Documentation

This document provides a comprehensive overview of the robot circuit used for the World Robot Olympiad (WRO) Future Engineers 2024 competition. The circuit includes various components such as the Raspberry Pi, Arduino Nano, L298N motor driver, sensors, and power management elements. This guide covers the wiring, communication protocols, and component roles within the system.

Robot Circuit Diagram

## Table of Contents

- [Components](#components)
- [Power Management](#power-management)
  - [7806 Voltage Regulator with Capacitors](#7806-voltage-regulator-with-capacitors)
  - [Buck Converter](#buck-converter)
- [Communication Protocols](#communication-protocols)
  - [I2C Communication](#i2c-communication)
  - [USB Serial Communication](#usb-serial-communication)
  - [UART Communication (TX/RX)](#uart-communication-tx-rx)
  - [PWM Signals](#pwm-signals)
- [Component Connections](#component-connections)
- [System Architecture and Data Flow](#system-architecture-and-data-flow)

---

## Components

The primary components in the circuit include:

1. **Raspberry Pi**: Main control and processing unit.
2. **Arduino Nano**: Microcontroller handling low-level sensor operations and communication with the Raspberry Pi.
3. **L298N Motor Driver**: Controls a 12V DC motor with magnetic encoders.
4. **12V DC Motor with Magnetic Encoders**: Drives the robot’s wheels, with encoder feedback for precise control.
5. **LiPo Battery (3S, 50C, 2.2Ah, 11.1V)**: High-capacity power source for the entire system.
6. **7806 Voltage Regulator**: Provides a stable 6V output for the servo motor.
7. **Two 470 µF Capacitors**: Connected to the 7806 for voltage stabilization and filtering.
8. **Buck Converter (11.1V to 5V)**: Supplies 5V power to the Raspberry Pi.
9. **DTOF (Distance Time-of-Flight) Sensors (I2C)**: Measures distances to obstacles.
10. **MPU6050 (Gyroscope/Accelerometer)**: Measures orientation and motion.
11. **Servo Motor**: Controls small actuators or sensor positioning.
12. **Buzzer**: Provides audio feedback.
13. **Camera Module**: Provides video input for image processing.
14. **LiDAR Sensor**: High-precision distance measurement for mapping or navigation.
15. **Switches**: Controls power delivery to different components manually.

---

## Power Management

### 7806 Voltage Regulator with Capacitors

The **7806 voltage regulator** is used to convert the LiPo battery voltage (11.1V) to a stable 6V output, powering the servo motor.

- **Input**: Connected to the 11.1V LiPo battery output.
- **Output**: Provides 6V for the servo motor.
- **Capacitors for Stabilization and Filtering**:
  - **Two 470 µF Capacitors** are connected to the 7806 voltage regulator to help stabilize the output voltage and filter out any noise. One capacitor is placed across the input and ground, and the other across the output and ground.
- **Grounding**: The 7806 ground pin connects to the shared ground of the entire circuit.

### Buck Converter (11.1V to 5V)

A **buck converter** steps down the 11.1V from the LiPo battery to a stable 5V to supply power to the Raspberry Pi.

- **Input**: Connected to the 11.1V LiPo battery.
- **Output**: Provides 5V power to the Raspberry Pi.
- **Grounding**: Connected to the common ground of the circuit.

---

## Communication Protocols

### I2C Communication

The **I2C protocol** is used to connect multiple sensors to the same bus, allowing communication with the Arduino Nano through two main lines: SCL (Clock) and SDA (Data). Each sensor has a unique address on the bus.

- **Components using I2C**:
  - **DTOF Sensors**: Four Time-of-Flight sensors for obstacle detection, each with a unique I2C address.
  - **MPU6050**: Provides data on orientation and movement.
- **Wiring**:
  - **SCL (Clock)**: Shared by all I2C devices, connected to the SCL pin on the Arduino.
  - **SDA (Data)**: Shared by all I2C devices, connected to the SDA pin on the Arduino.

### USB Serial Communication

**USB Serial Communication** is used for direct data transfer between the **Raspberry Pi** and **Arduino Nano**.

- The USB cable connects the Raspberry Pi and Arduino Nano, enabling bidirectional data transfer.

### UART Communication (TX/RX)

**UART (Universal Asynchronous Receiver/Transmitter)** is used for communication between the **LiDAR sensor** and **Raspberry Pi**.

- **Wiring**:
  - **TX (Transmit)** on the LiDAR to **RX (Receive)** on the Raspberry Pi.
  - **RX (Receive)** on the LiDAR to **TX (Transmit)** on the Raspberry Pi.

### PWM Signals

**PWM (Pulse Width Modulation)** signals are used to control both the motor driver and servo.

- **Motor Driver (L298N)**: Receives PWM signals from the Arduino Nano to adjust the speed of the 12V DC motor.
- **Servo Motor**: Controlled by the Arduino Nano using PWM for precise angle positioning.

---

## Component Connections

All components, except the camera and LiDAR, are connected to the **Arduino Nano**. This includes the motor driver, DTOF sensors, MPU6050, servo motor, and buzzer. The **Raspberry Pi** is only connected to the **camera module** (via the CSI port) and **LiDAR sensor** (via UART TX/RX), handling high-level processing and vision tasks.

### Raspberry Pi

- **GPIO**:
  - Communicates with the Arduino Nano via USB Serial.
  - Communicates with the LiDAR sensor via UART (TX/RX).
  - Powers the camera module for real-time image processing through the CSI port.

### Arduino Nano

- **I2C Bus**: Connects to the MPU6050 and Time-of-Flight distance sensors.
- **PWM**:
  - Controls the servo motor for actuation.
  - Drives the buzzer for audio signals.
- **GPIO for Motor Control**:
  - Connected to the L298N motor driver to control the 12V DC motor with PWM signals.

---

## System Architecture and Data Flow

1. **Power Supply**:
   - The LiPo battery (11.1V, 3S, 50C, 2.2Ah) provides power to high-current components like the motor driver and motor.
   - The 7806 voltage regulator, along with two 470 µF capacitors, supplies a stable 6V output to the servo motor.
   - The buck converter steps down the battery voltage to 5V to power the Raspberry Pi.

2. **Sensor Data Collection**:
   - The Arduino Nano collects data from all I2C sensors (MPU6050, DTOF sensors) and controls the motor, servo, and buzzer.
   - The data from these sensors is processed by the Arduino or transmitted to the Raspberry Pi via USB Serial.

3. **High-Level Processing**:
   - The Raspberry Pi performs high-level tasks such as video processing and complex decision-making.
   - Image data from the camera module is processed using computer vision libraries like OpenCV.
   - The Raspberry Pi receives distance data from the LiDAR sensor for navigation and obstacle avoidance.

4. **Control Flow**:
   - The Arduino Nano sends PWM signals to the L298N motor driver to control the 12V DC motor.
   - It also controls the servo motor and buzzer based on feedback from sensors.
   - The Raspberry Pi communicates with the Arduino Nano and sends additional commands as needed.

5. **Decision Making**:
   - Data from the LiDAR, DTOF sensors, and MPU6050 help in obstacle detection and path planning.
   - Based on this information, the Raspberry Pi and Arduino Nano coordinate actions, such as steering the robot or adjusting speed.

---

This circuit provides a robust foundation for an autonomous robot with sensing, communication, and motor control. By using both the Raspberry Pi and Arduino Nano, the system effectively distributes processing loads, with the Raspberry Pi focused on high-level vision and navigation and the Arduino Nano managing other essential components.

---

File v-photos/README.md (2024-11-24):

<table>
  <tr>
    <td>
      Top View
      <p style="text-align: center; font-size: 24px; font-weight: bold;">Isometric View</p>
    </td>
  </tr>
</table>

<table>
  <tr>
    <td>
      Top View
      <p style="text-align: center; font-size: 24px; font-weight: bold;">Top View</p>
    </td>
    <td>
      Bottom View
      <p style="text-align: center; font-size: 24px; font-weight: bold;">Bottom View</p>
    </td>
  </tr>
  <tr>
    <td>
      <img src=https://github.com/DexterTaha/WRO-FE-2024-Mindcraft-International/blob/main/v-photos/real%20images/Right-view.jpg" alt="Front View" height="300">
      <p style="text-align: center; font-size: 24px; font-weight: bold;">Right View</p>
    </td>
    <td>
      Left View
      <p style="text-align: center; font-size: 24px; font-weight: bold;">Left View</p>
    </td>
  </tr>
  <tr>
    <td>
      
      <p style="text-align: center; font-size: 24px; font-weight: bold;">Face View</p>
    </td>
    <td>
      Right View
      <p style="text-align: center; font-size: 24px; font-weight: bold;">Rear View</p>
    </td>
  </tr>
</table>

<table>
  <tr>
    <td>
      ROBOT ISOMETRIC VIEW
      <p style="text-align: center; font-size: 24px; font-weight: bold;">Isometric View</p>
    </td>
  </tr>
</table>

<table>
  <tr>
    <td>
      ROBOT TOP VIEW
      <p style="text-align: center; font-size: 24px; font-weight: bold;">Top View</p>
    </td>
    <td>
      ROBOT BOTTOM VIEW
      <p style="text-align: center; font-size: 24px; font-weight: bold;">Bottom View</p>
    </td>
  </tr>
  <tr>
    <td>
      ROBOT RIGHT VIEW
      <p style="text-align: center; font-size: 24px; font-weight: bold;">Right View</p>
    </td>
    <td>
      ROBOT LEFT VIEW
      <p style="text-align: center; font-size: 24px; font-weight: bold;">Left View</p>
    </td>
  </tr>
  <tr>
    <td>
      ROBOT FACE VIEW
      <p style="text-align: center; font-size: 24px; font-weight: bold;">Face View</p>
    </td>
    <td>
      ROBOT REAR VIEW
      <p style="text-align: center; font-size: 24px; font-weight: bold;">Rear View</p>
    </td>
  </tr>
</table>

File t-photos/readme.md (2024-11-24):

<h3>Mindcraft Engineers Team Pic</h3>
<div align="center">
    Engineers Github
</div>

<h3>OUR Team Fun Pic 🤦‍♂️</h3>
<div align="center">
    Team Fun Pic
    <p>Our team's fun moment captured perfectly!</p>
</div>

<h3>team members</h3>

<table border="1" style="width: 100%; border-collapse: collapse;">
    <thead>
        <tr>
            <th style="text-align: center; vertical-align: middle; width: 25%;">👤 NAME</th>
            <th style="text-align: center; vertical-align: middle; width: 25%;">DERDEB Salmane</th>
            <th style="text-align: center; vertical-align: middle; width: 25%;">TAIDI LAAMIRI TAHA</th>
            <th style="text-align: center; vertical-align: middle; width: 25%;">TAIDI LAAMIRI MORTADA</th>
        </tr>
    </thead>
    <tbody>
        <tr>
            <td style="text-align: center; vertical-align: middle;">🖼️ IMAGE</td>
            <td style="text-align: center; vertical-align: middle;">
                Salman Derdeb
            </td>
            <td style="text-align: center; vertical-align: middle;">
                Taha Taidi Laamiri
            </td>
            <td style="text-align: center; vertical-align: middle;">
                Mortada Taidi Laamiri
            </td>
        </tr>
        <tr>
            <td style="text-align: center; vertical-align: middle;">🔢 AGE</td>
            <td style="text-align: center; vertical-align: middle;">15 YEARS OLD</td>
            <td style="text-align: center; vertical-align: middle;">19 YEARS OLD</td>
            <td style="text-align: center; vertical-align: middle;">16 YEARS OLD</td>
        </tr>
        <tr>
            <td style="text-align: center; vertical-align: middle;">🎓 STUDIES</td>
            <td style="text-align: center; vertical-align: middle;">10th Grade Scientific (French Option) Student</td>
            <td style="text-align: center; vertical-align: middle;">Industrial Engineering Student + Automated System Degree</td>
            <td style="text-align: center; vertical-align: middle;">11th Grade Physics and Math (French Option) Student</td>
        </tr>
        <tr>
            <td style="text-align: center; vertical-align: middle;">🎯 ROLE</td>
            <td style="text-align: center; vertical-align: middle;">Computer Vision and Programming Lead</td>
            <td style="text-align: center; vertical-align: middle;">Team Leader, Electrical and Electronics Lead</td>
            <td style="text-align: center; vertical-align: middle;">Fabrication and Conception Lead</td>
        </tr>
        <tr>
            <td style="text-align: center; vertical-align: middle;">🌐 LANGUAGE</td>
            <td style="text-align: center; vertical-align: middle;">
                <ul style="list-style-type: none; padding-left: 0;">
                    <li>Arabic: Native</li>
                    <li>French: Very Good</li>
                    <li>English: Very Good</li>
                    <li>Turkish: Intermediate</li>
                </ul>
            </td>
            <td style="text-align: center; vertical-align: middle;">
                <ul style="list-style-type: none; padding-left: 0;">
                    <li>Arabic: Native</li>
                    <li>French: Very Good</li>
                    <li>English: Very Good</li>
                </ul>
            </td>
            <td style="text-align: center; vertical-align: middle;">
                <ul style="list-style-type: none; padding-left: 0;">
                    <li>Arabic: Native</li>
                    <li>French: Good</li>
                    <li>English: Beginner</li>
                </ul>
            </td>
        </tr>
        <tr>
            <td style="text-align: center; vertical-align: top;">🛠️ RESPONSIBILITIES</td>
            <td style="text-align: center; vertical-align: top;">
                <ul style="list-style-type: disc; padding-left: 20px;">
                    <li>Lead the development and implementation of computer vision algorithms.</li>
                    <li>Handle general programming, ensuring software works with hardware.</li>
                    <li>Create and edit videos, graphics, and team content.</li>
                    <li>Produce 3D animations using Blender for project visuals.</li>
                    <li>Document work on GitHub and maintain the physical engineering notebook.</li>
                </ul>
            </td>
            <td style="text-align: center; vertical-align: top;">
                <ul style="list-style-type: disc; padding-left: 20px;">
                    <li>Oversee team tasks and ensure deadlines are met.</li>
                    <li>Facilitate communication between team members.</li>
                    <li>Conduct technical study and oversee engineering of the robot.</li>
                    <li>Design and create the PCB and handle electronics connections.</li>
                    <li>Perform component compatibility calculations.</li>
                    <li>Manage the Bill of Materials (BOM) and component sourcing.</li>
                    <li>Document project progress on GitHub.</li>
                </ul>
            </td>
            <td style="text-align: center; vertical-align: top;">
                <ul style="list-style-type: disc; padding-left: 20px;">
                    <li>Take measurements for robot components.</li>
                    <li>Design and 3D print components.</li>
                    <li>Lead robot assembly and manage mechanical parts.</li>
                    <li>Test, iterate, and improve design versions.</li>
                    <li>Document work on GitHub.</li>
                </ul>
            </td>
        </tr>
        <tr>
            <td style="text-align: center; vertical-align: top;">🛠️ TOOLS AND SOFTWARE</td>
            <td style="text-align: left; vertical-align: top;">
                <ul style="list-style-type: none; padding-left: 0;">
                    <li>GitHub GitHub</li>
                    <li>HTML HTML</li>
                    <li>CSS CSS</li>
                    <li>SCSS SCSS</li>
                    <li>JavaScript JavaScript</li>
                    <li>React React</li>
                    <li>Bootstrap Bootstrap</li>
                    <li>Figma Figma</li>
                     <li>C C</li>
                    <li>C++ C++</li>
                    <li>Python Python</li>
                     <li>Linux Linux</li>
                    <li>Ubuntu Ubuntu</li>
                    <li>Raspberry Pi Raspberry Pi</li>
                </ul>
            </td>
            <td style="text-align: left; vertical-align: top;">
                <ul style="list-style-type: none; padding-left: 0;">
                    <li>GitHub GitHub</li>
                    <li>HTML HTML</li>
                    <li>CSS CSS</li>
                    <li>SCSS SCSS</li>
                    <li>JavaScript JavaScript</li>
                    <li>React React</li>
                    <li>Bootstrap Bootstrap</li>
                    <li>Figma Figma</li>
                     <li>C C</li>
                    <li>C++ C++</li>
                    <li>Python Python</li>
                     <li>Linux Linux</li>
                    <li>Ubuntu Ubuntu</li>
                    <li>Raspberry Pi Raspberry Pi</li>
                </ul>
            </td>
            <td style="text-align: left; vertical-align: top;">
                <ul style="list-style-type: none; padding-left: 0;">
                    <li>GitHub GitHub</li>
                    <li>HTML HTML</li>
                    <li>CSS CSS</li>
                    <li>JavaScript JavaScript</li>
                    <li>Figma Figma</li>
                    <li>Blender Blender</li>
                    <li>Creality Print Onshape</li>
                    <li>Onshape creality print
                            <li>
                                <li>
                                    <li>
                                        <li>
                                            <li><li>
                                                <li>
                                                    <li>
                            <li>
                </ul>
            </td>
        </tr>
        <tr>
            <th style="text-align: center; vertical-align: middle; width: 25%;">🐈‍⬛ GITHUB Profile</th>
            <th style="text-align: center; vertical-align: middle; width: 25%;"><a href="https://github.com/salmane-derdeb">Salmane Derdeb</a></th>
            <th style="text-align: center; vertical-align: middle; width: 25%;"><a href="https://github.com/DexterTaha">Taha TAIDI LAAMIRI</a></th>
            <th style="text-align: center; vertical-align: middle; width: 25%;"><a href="https://github.com/taidimortada">Mortada TAIDI LAAMIRI</a></th>
        </tr>
    </tbody>
</table>

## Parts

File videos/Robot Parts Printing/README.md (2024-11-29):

### Robot Parts Printing

https://www.youtube.com/playlist?list=PLf8kIvXqxCoA1BqdyIc0BufjEty1oEdxA

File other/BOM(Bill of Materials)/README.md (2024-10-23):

<body>
    <h1>Bill of Materials</h1>
    <table>
        <thead>
            <tr>
                <th>Code</th>
                <th>Name</th>
                <th>Datasheet</th>
                <th>Setup</th>
                <th>3D Model</th>
                <th>Description</th>
                <th>Image</th>
            </tr>
        </thead>
        <tbody>
            <tr>
                <td data-label="Code">0x00</td>
                <td data-label="Name">Raspberry Pi 4B</td>
                <td data-label="Datasheet"><a href="https://github.com/DexterTaha/WRO-FE-2024-Mindcraft-International/tree/9ad9d503698aa839e118a1041bc7e58b6689c99e/other/component%20Details/0x00-Raspberry%20Pi%204B/Da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">Datasheet</a></td>
                <td data-label="Setup"><a href="https://github.com/DexterTaha/WRO-FE-2024-Mindcraft-International/tree/9ad9d503698aa839e118a1041bc7e58b6689c99e/other/component%20Details/0x00-Raspberry%20Pi%204B/Se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">Setup</a></td>
                <td data-label="3D Model"><a href="https://developer.nvidia.com/embedded/learn/jetson-nano-3d-models">3D Model</a></td>
                <td data-label="Description">Main computing unit</td>
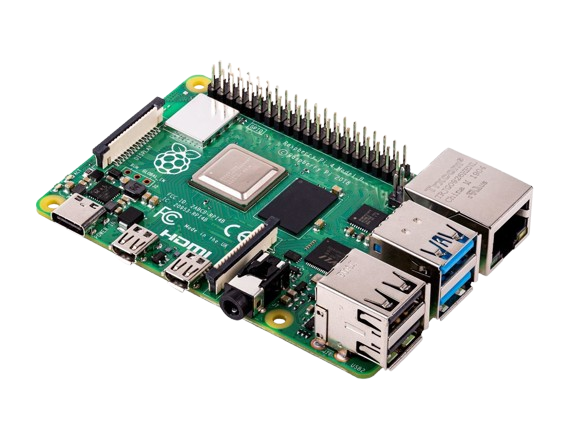
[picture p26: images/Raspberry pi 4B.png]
Raspberry
                <td data-label="Image"></td>
            </tr>
            <tr>
                <td data-label="Code">0x01</td>
                <td data-label="Name">Arduino NANO</td>
                <td data-label="Datasheet"><a href="https://github.com/DexterTaha/WRO-FE-2024-Mindcraft-International/tree/47bf23bfe6a8f57052bee0b2b33903a335146ad1/other/component%20Details/0x01-Arduino%20NANO/Datashe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">Datasheet</a></td>
                <td data-label="Setup"><a href="https://github.com/DexterTaha/WRO-FE-2024-Mindcraft-International/tree/47bf23bfe6a8f57052bee0b2b33903a335146ad1/other/component%20Details/0x01-Arduino%20NANO/Setup">Setup</a></td>
                <td data-label="3D Model"><a href="https://cad.onshape.com/documents/1c6f1405e84d0c390333223c/w/c90b719cdc670bdbfb16a84e/e/58c1c76865cebcf7f2c0d9cc">3D Model</a></td>
                <td data-label="Description">Microcontroller</td>
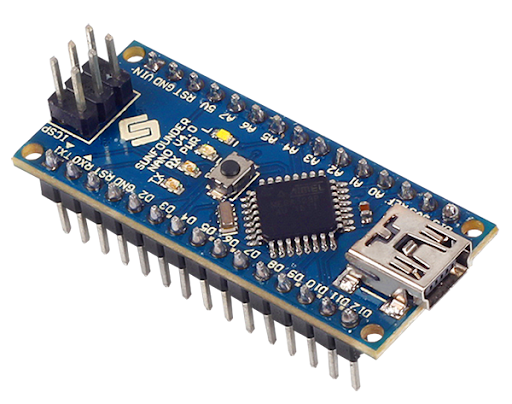
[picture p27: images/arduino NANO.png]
Arduino Nano
                <td data-label="Image"></td>
            </tr>
            <tr>
                <td data-label="Code">0x02</td>
                <td data-label="Name">LIDAR</td>
                <td data-label="Datasheet"><a href="https://github.com/DexterTaha/WRO-FE-2024-Mindcraft-International/tree/47bf23bfe6a8f57052bee0b2b33903a335146ad1/other/component%20Details/0x02-LIDAR/Datasheet">Datasheet</a></td>
                <td data-label="Setup"><a href="https://github.com/DexterTaha/WRO-FE-2024-Mindcraft-International/tree/47bf23bfe6a8f57052bee0b2b33903a335146ad1/other/component%20Details/0x02-LIDAR/Setup">Setup</a></td>
                <td data-label="3D Model"><a href="https://cad.onshape.com/documents/2729187d74795f5505a642cc/w/3e0c0cce82870e83e2fa6638/e/bc5a610b18bbd2f7644b07b9">3D Model</a></td>
                <td data-label="Description">Laser Range Sensor</td>
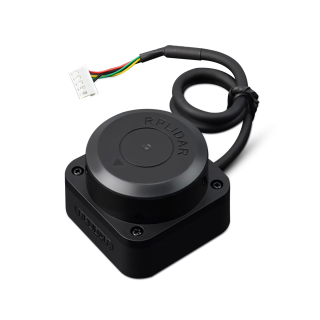
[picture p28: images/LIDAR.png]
LIDAR
                <td data-label="Image"></td>
            </tr>
            <tr>
                <td data-label="Code">0x03</td>
                <td data-label="Name">Distance Sensor VL53L1X</td>
                <td data-label="Datasheet"><a href="https://github.com/DexterTaha/WRO-FE-2024-Mindcraft-International/tree/47bf23bfe6a8f57052bee0b2b33903a335146ad1/other/component%20Details/0x03-Distance%20Sensor%20VL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">Datasheet</a></td>
                <td data-label="Setup"><a href="https://github.com/DexterTaha/WRO-FE-2024-Mindcraft-International/tree/47bf23bfe6a8f57052bee0b2b33903a335146ad1/other/component%20Details/0x03-Distance%20Sensor%20VL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">Setup</a></td>
                <td data-label="3D Model"><a href="https://cad.onshape.com/documents/1c6f1405e84d0c390333223c/w/c90b719cdc670bdbfb16a84e/e/94e51bc799b10763631d10cb">3D Model</a></td>
                <td data-label="Description">Time-of-Flight Distance Sensor</td>
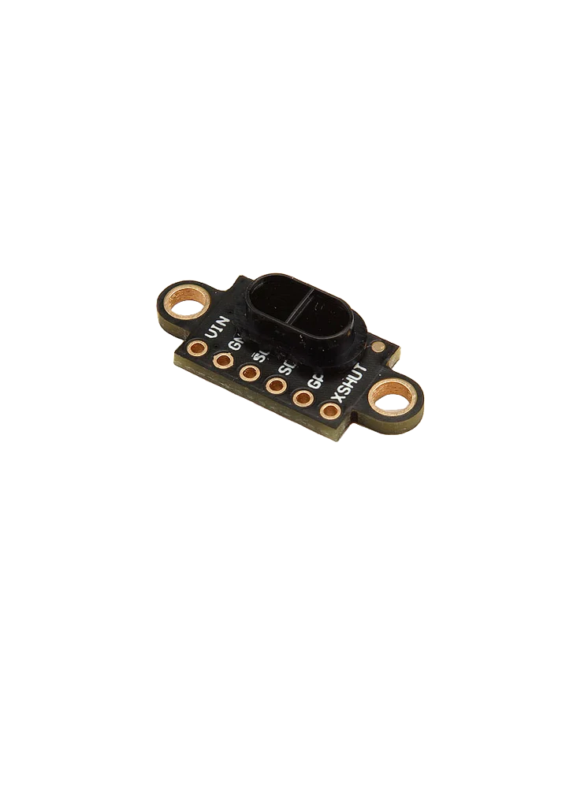
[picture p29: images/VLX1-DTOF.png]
VL53L1X
                <td data-label="Image"></td>
            </tr>
            <tr>
                <td data-label="Code">0x04</td>
                <td data-label="Name">GYROSCOPE Sensor MPU6050</td>
                <td data-label="Datasheet"><a href="https://github.com/DexterTaha/WRO-FE-2024-Mindcraft-International/tree/47bf23bfe6a8f57052bee0b2b33903a335146ad1/other/component%20Details/0x04-GYROSCOPE%20Sensor%20M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">Datasheet</a></td>
                <td data-label="Setup"><a href="https://github.com/DexterTaha/WRO-FE-2024-Mindcraft-International/tree/47bf23bfe6a8f57052bee0b2b33903a335146ad1/other/component%20Details/0x04-GYROSCOPE%20Sensor%20M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">Setup</a></td>
                <td data-label="3D Model"><a href="https://cad.onshape.com/documents/1c6f1405e84d0c390333223c/w/c90b719cdc670bdbfb16a84e/e/5080605618051d13a916ba3c">3D Model</a></td>
                <td data-label="Description">6-axis Gyroscope and Accelerometer</td>
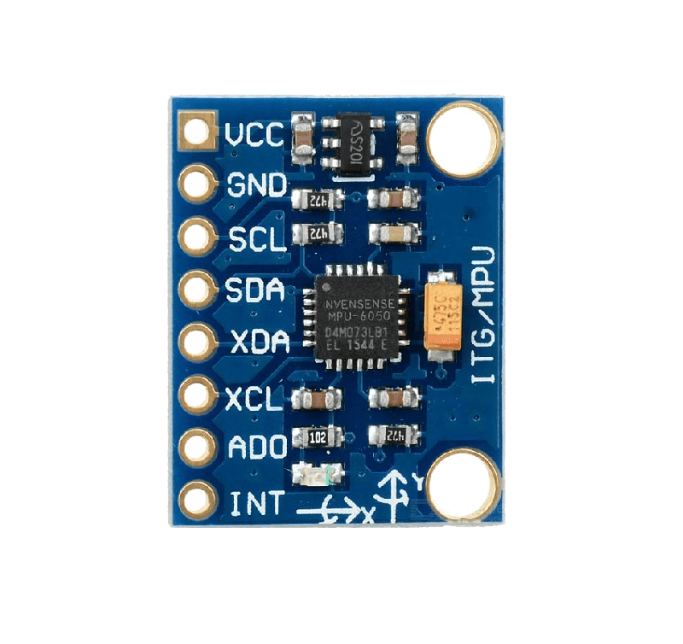
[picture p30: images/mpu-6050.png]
MPU6050
                <td data-label="Image"></td>
            </tr>
            <tr>
                <td data-label="Code">0x05</td>
                <td data-label="Name">Camera</td>
                <td data-label="Datasheet"><a href="https://github.com/DexterTaha/WRO-FE-2024-Mindcraft-International/tree/47bf23bfe6a8f57052bee0b2b33903a335146ad1/other/component%20Details/0x05-Camera/Datasheet/">Datasheet</a></td>
                <td data-label="Setup"><a href="https://github.com/DexterTaha/WRO-FE-2024-Mindcraft-International/tree/84b82731468978746051cf060b159d2cc26e164f/other/component%20Details/0x05-Camera/Setup">Setup</a></td>
                <td data-label="3D Model"><a href="https://www.thingiverse.com/thing:2970128">3D Model</a></td>
                <td data-label="Description">Camera module</td>
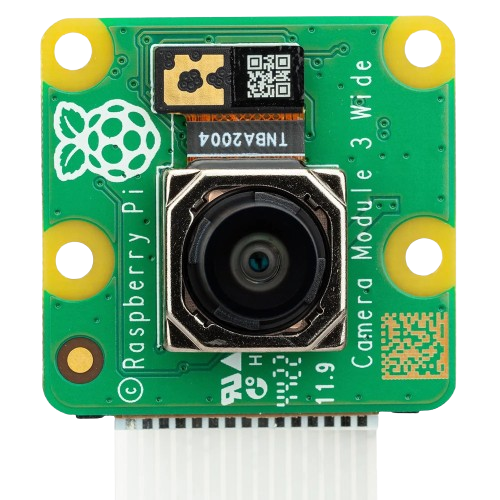
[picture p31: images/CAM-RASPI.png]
Camera
                <td data-label="Image"></td>
            </tr>
            <tr>
                <td data-label="Code">0x06</td>
                <td data-label="Name">DC Brushed Motor with Encoder</td>
                <td data-label="Datasheet"><a href="https://github.com/DexterTaha/WRO-FE-2024-Mindcraft-International/tree/84b82731468978746051cf060b159d2cc26e164f/other/component%20Details/0x06-DC%20Brushed%20Motor%2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">Datasheet</a></td>
                <td data-label="Setup"><a href="https://github.com/DexterTaha/WRO-FE-2024-Mindcraft-International/tree/84b82731468978746051cf060b159d2cc26e164f/other/component%20Details/0x06-DC%20Brushed%20Motor%2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">Setup</a></td>
                <td data-label="3D Model"><a href="https://cad.onshape.com/documents/1c6f1405e84d0c390333223c/w/c90b719cdc670bdbfb16a84e/e/bc317ffe6fa7f5ad89df3856">3D Model</a></td>
                <td data-label="Description">Motor for movement with encoder feedback</td>
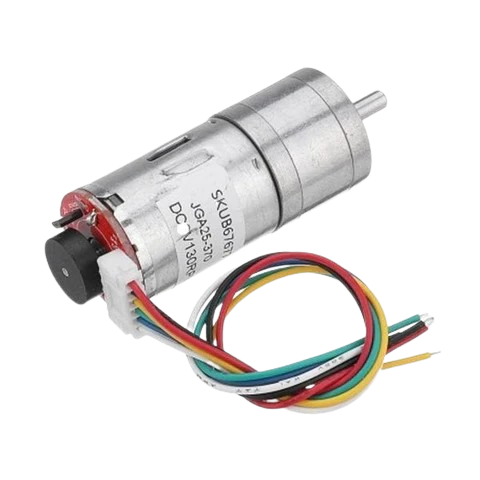
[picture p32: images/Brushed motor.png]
DC Motor with Encoder
                <td data-label="Image"></td>
            </tr>
            <tr>
                <td data-label="Code">0x07</td>
                <td data-label="Name">Wheels</td>
                <td data-label="Datasheet"><a href="https://www.robotshop.com/en/motor-wheels.html">Datasheet</a></td>
                <td data-label="Setup"><a href="https://www.robotshop.com/en/wheel-and-tread.html">Setup</a></td>
                <td data-label="3D Model"><a href="https://www.thingiverse.com/thing:1864586">3D Model</a></td>
                <td data-label="Description">Wheels for robot movement</td>
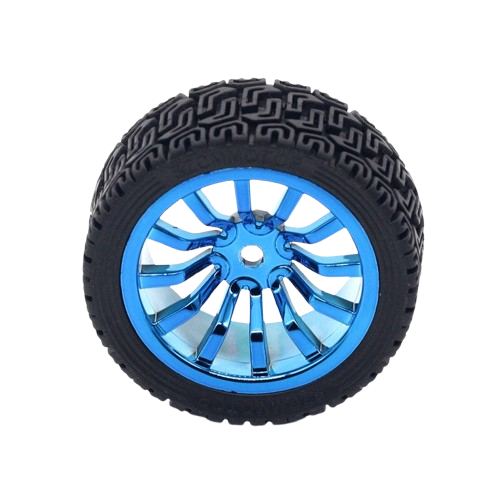
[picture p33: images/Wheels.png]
Wheels
                <td data-label="Image"></td>
            </tr>
            <tr>
                <td data-label="Code">0x08</td>
                <td data-label="Name">L298 Motor Driver</td>
                <td data-label="Datasheet"><a href="https://github.com/DexterTaha/WRO-FE-2024-Mindcraft-International/tree/67650b7d72705afa8f343d58dabc49bec869e66c/other/component%20Details/0x08-L298N%20Motor%20driver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">Datasheet</a></td>
                <td data-label="Setup"><a href="https://github.com/DexterTaha/WRO-FE-2024-Mindcraft-International/tree/67650b7d72705afa8f343d58dabc49bec869e66c/other/component%20Details/0x08-L298N%20Motor%20driver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">Setup</a></td>
                <td data-label="3D Model"><a href="https://www.thingiverse.com/thing:1864586">3D Model</a></td>
                <td data-label="Description">Command Motor High Voltage with logic voltage 5v</td>
                <td data-label="Image">Wheels</td>
            </tr>
            <tr>
                <td data-label="Code">0x09</td>
                <td data-label="Name">Servo motor Metal Gear Box 180°</td>
                <td data-label="Datasheet"><a href="https://github.com/DexterTaha/WRO-FE-2024-Mindcraft-International/tree/67650b7d72705afa8f343d58dabc49bec869e66c/other/component%20Details/0x09-Servo%20motor%20Metal%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">Datasheet</a></td>
                <td data-label="Setup"><a href="https://github.com/DexterTaha/WRO-FE-2024-Mindcraft-International/tree/67650b7d72705afa8f343d58dabc49bec869e66c/other/component%20Details/0x09-Servo%20motor%20Metal%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">Setup</a></td>
                <td data-label="3D Model"><a href="https://www.thingiverse.com/thing:1864586">3D Model</a></td>
                <td data-label="Description">For Robot turning</td>
                <td data-label="Image">Wheels</td>
            </tr>
            <tr>
                <td>0x10</td>
                <td>5V Power Converter</td>
                <td><a href="https://github.com/DexterTaha/WRO-FE-2024-Mindcraft-International/tree/d3d67aaae2e988e7a49f0e28bd44e6e8cd050f9c/other/component%20Details/0x10-5V%20Power%20Converter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">Datasheet</a></td>
                <td><a href="https://github.com/DexterTaha/WRO-FE-2024-Mindcraft-International/tree/d3d67aaae2e988e7a49f0e28bd44e6e8cd050f9c/other/component%20Details/0x10-5V%20Power%20Converter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">Setup</a></td>
                <td><a href="https://www.thingiverse.com/thing:1864586">3D Model</a></td>
                <td>5V Power Converter</td>
                <td>Lipo Battery</td>
            </tr>
            <tr>
            <tr>
                <td>0x11</td>
                <td>Lipo 3S 2200mah 11.1V 50C</td>
                <td><a href="https://www.hobbyking.com/hobbyking/store/__17356__Turnigy_2200mAh_3S_20C_Lipo_Pack.html">Datasheet</a></td>
                <td>N/A</td>
                <td><a href="https://www.thingiverse.com/thing:1864586">3D Model</a></td>
                <td>Lithium Polymer Battery</td>
                <td>Lipo Battery</td>
            </tr>
            <tr>
                <td>0x12</td>
                <td>IMAX B6AC V2</td>
                <td><a href="https://www.skyrc.com/Charger/B6AC_V2">Datasheet</a></td>
                <td><a href="https://manuals.skyrc.com/B6AC%20V2.pdf">Setup</a></td>
                <td><a href="https://www.thingiverse.com/thing:1864586">3D Model</a></td>
                <td>Battery Charger</td>
                <td>IMAX Charger</td>
            </tr>
            <tr>
                <td>0x13</td>
                <td>7806 Transistor</td>
                <td><a href="https://www.onsemi.com/pdf/datasheet/l78-d.pdf">Datasheet</a></td>
                <td>N/A</td>
                <td><a href="https://www.thingiverse.com/thing:1864586">3D Model</a></td>
                <td>6V Voltage Regulator</td>
                <td>7806 Transistor</td>
            </tr>
            <tr>
                <td>0x14</td>
                <td>Switch High Amper</td>
                <td><a href="https://docs.rs-online.com/1f89/0900766b814b93ef.pdf">Datasheet</a></td>
                <td>N/A</td>
                <td><a href="https://www.thingiverse.com/thing:1864586">3D Model</a></td>
                <td>High Current Switch</td>
                <td>Switch</td>
            </tr>
            <tr>
                <td>0x15</td>
                <td>Buzzer Alarm Batterie Lipo</td>
                <td><a href="https://www.hobbyking.com/hobbyking/store/__24786__Hobbyking_8482_Lipoly_Low_Voltage_Alarm_2S_3S.html">Datasheet</a></td>
                <td>N/A</td>
                <td><a href="https://www.thingiverse.com/thing:1864586">3D Model</a></td>
                <td>Lipo Battery Alarm</td>
                <td>Buzzer Alarm</td>
            </tr>
            <tr>
                <td>0x16</td>
                <td>Servo Tester</td>
                <td><a href="https://www.servocity.com/servo-tester/">Datasheet</a></td>
                <td>N/A</td>
                <td><a href="https://www.thingiverse.com/thing:1864586">3D Model</a></td>
                <td>Servo Motor Tester</td>
                <td>Servo Tester</td>
            </tr>
            <tr>
                <td>0x17</td>
                <td>Servobras</td>
                <td><a href="https://cad.onshape.com/documents/1c6f1405e84d0c390333223c/w/c90b719cdc670bdbfb16a84e/e/cf7c3951c0394e6adfc05022">Datasheet</a></td>
                <td>N/A</td>
                <td><a href="https://www.thingiverse.com/thing:1864586">3D Model</a></td>
                <td>Servo Arm</td>
                <td></td>
            </tr>
            <tr>
                <td>0x18</td>
                <td>SD Card 64GB</td>
                <td><a href="https://www.sandisk.com/home/memory-cards/microsd-cards">Datasheet</a></td>
                <td>N/A</td>
                <td><a href="https://www.thingiverse.com/thing:1864586">3D Model</a></td>
                <td>64GB SD Card</td>
                <td>SD Card</td>
            </tr>
            <tr>
                <td>0x19</td>
                <td>TPLink AC600</td>
                <td><a href="https://www.tp-link.com/us/home-networking/usb-adapter/archer-t2u/">Datasheet</a></td>
                <td><a href="https://static.tp-link.com/2018/201812/20181227/2018Q4_UG_T2U.pdf">Setup</a></td>
                <td><a href="https://www.thingiverse.com/thing:1864586">3D Model</a></td>
                <td>WiFi Adapter</td>
                <td>WiFi Adapter</td>
            </tr>
        </tbody>
    </table>
</body>
</html>

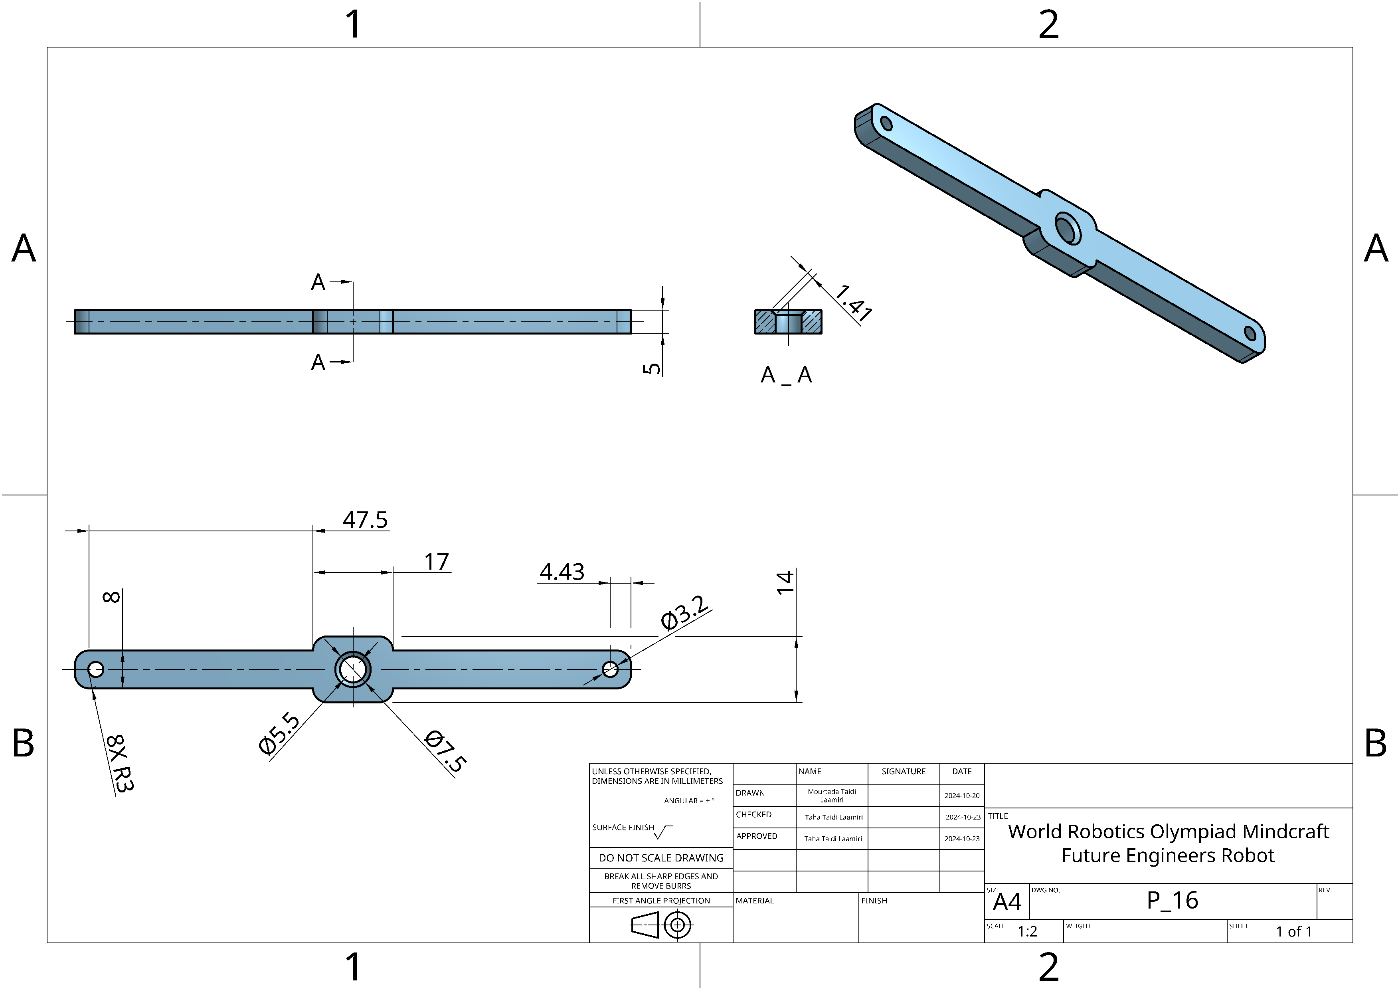
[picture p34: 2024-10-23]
Models/ Parts/0x08-Steering Rack/Drawing Steering Rack.png

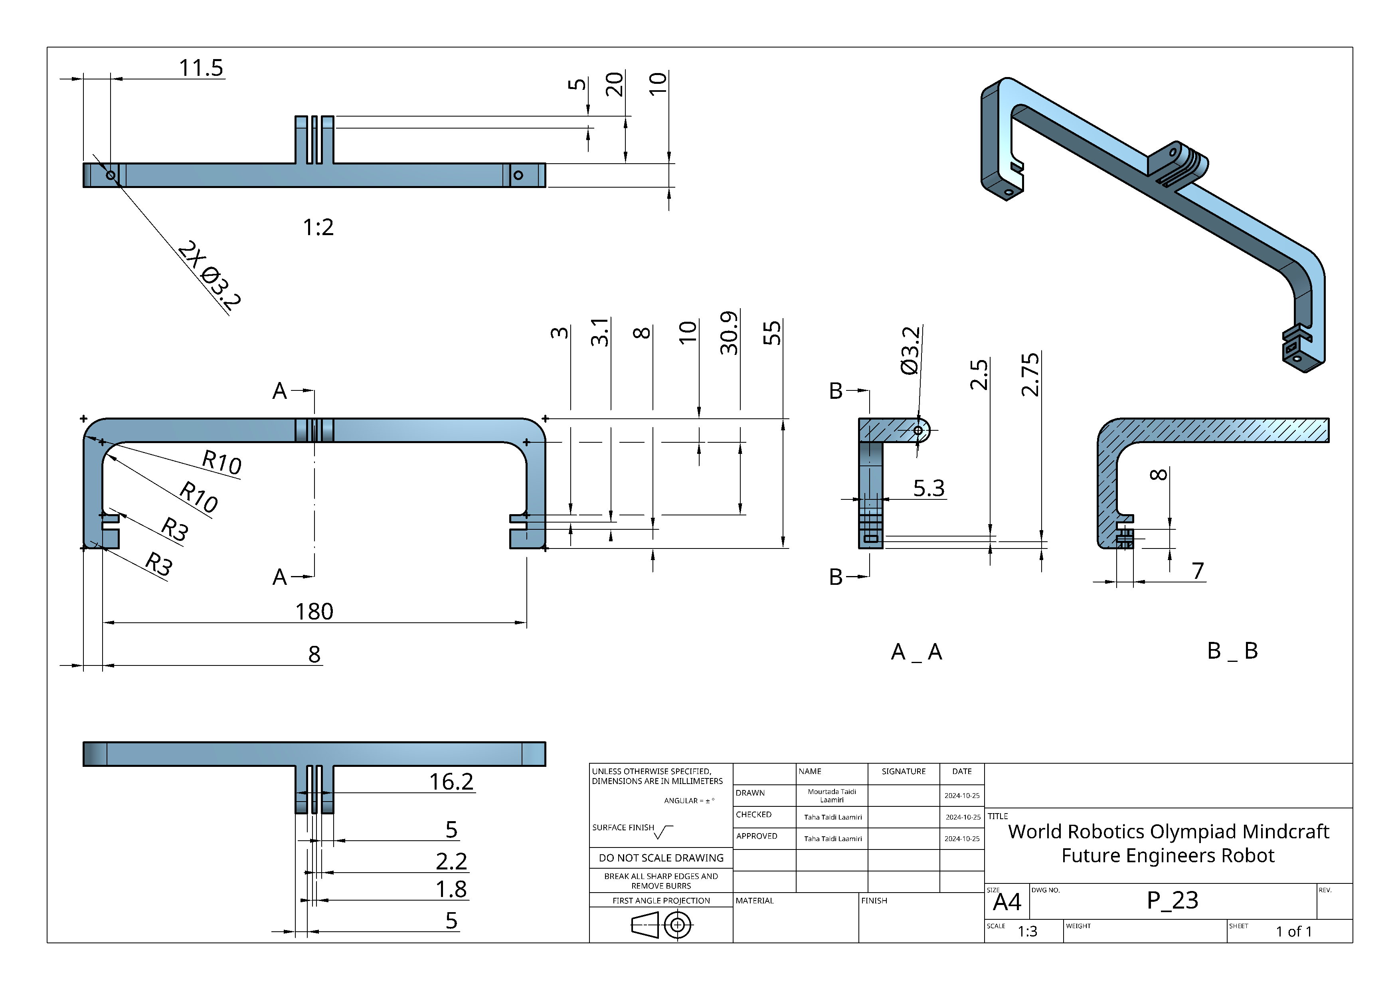
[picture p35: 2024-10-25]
Models/ Parts/0x15-Conector Support Camera/Drawing Conector Support Camera.png

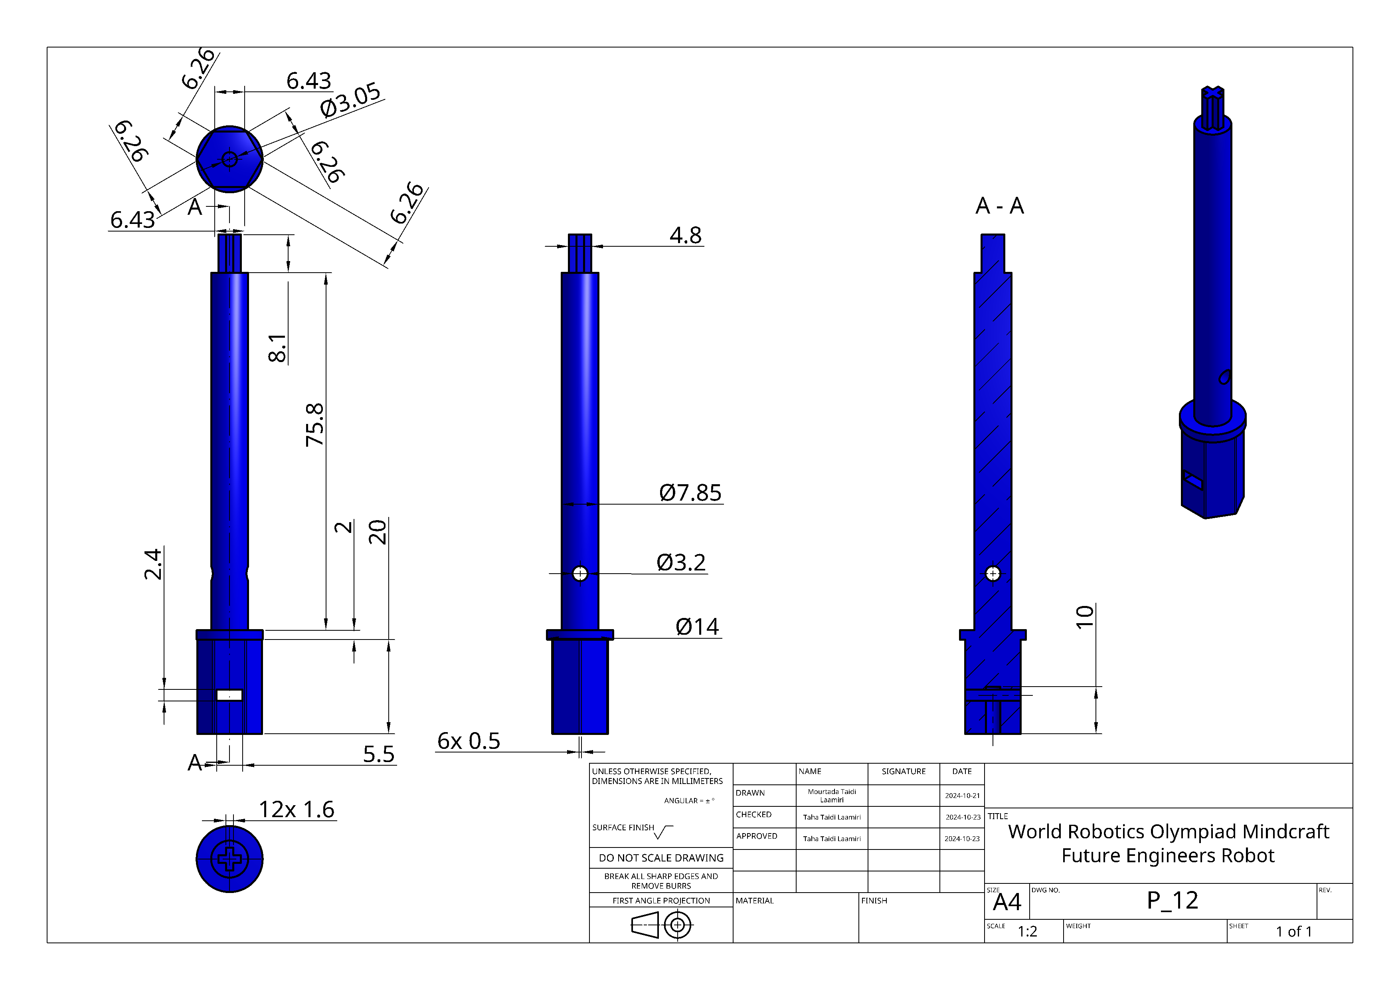
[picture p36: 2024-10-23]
Models/ Parts/0x04-Long Shaft/Drawing Long Shaft.png

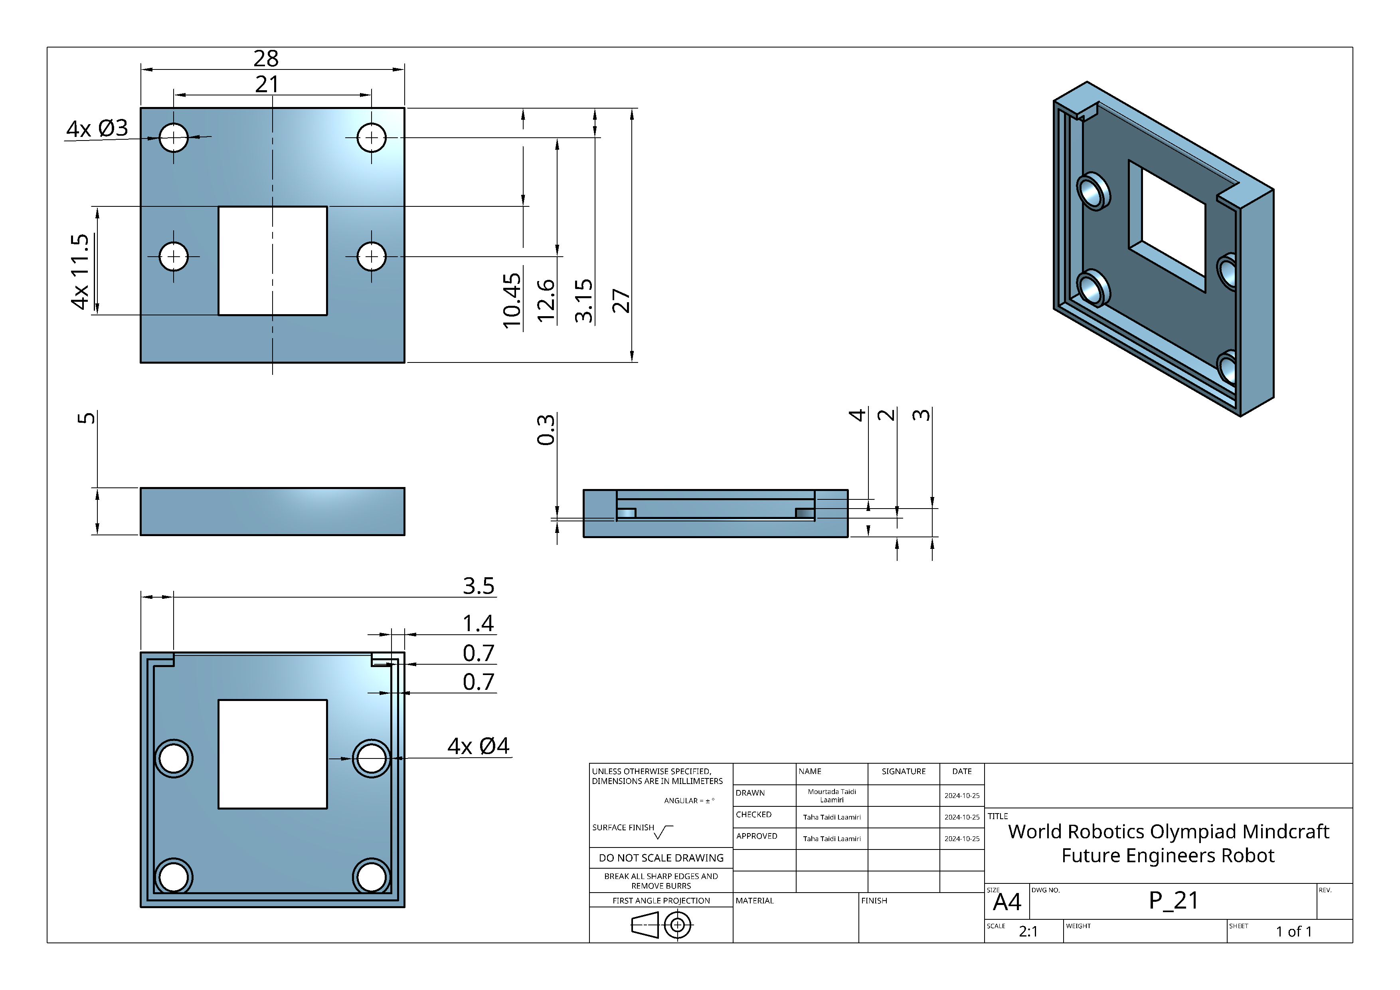
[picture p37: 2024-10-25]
Models/ Parts/0x13-Front Support Camera/Drawing Front Support Camera.png

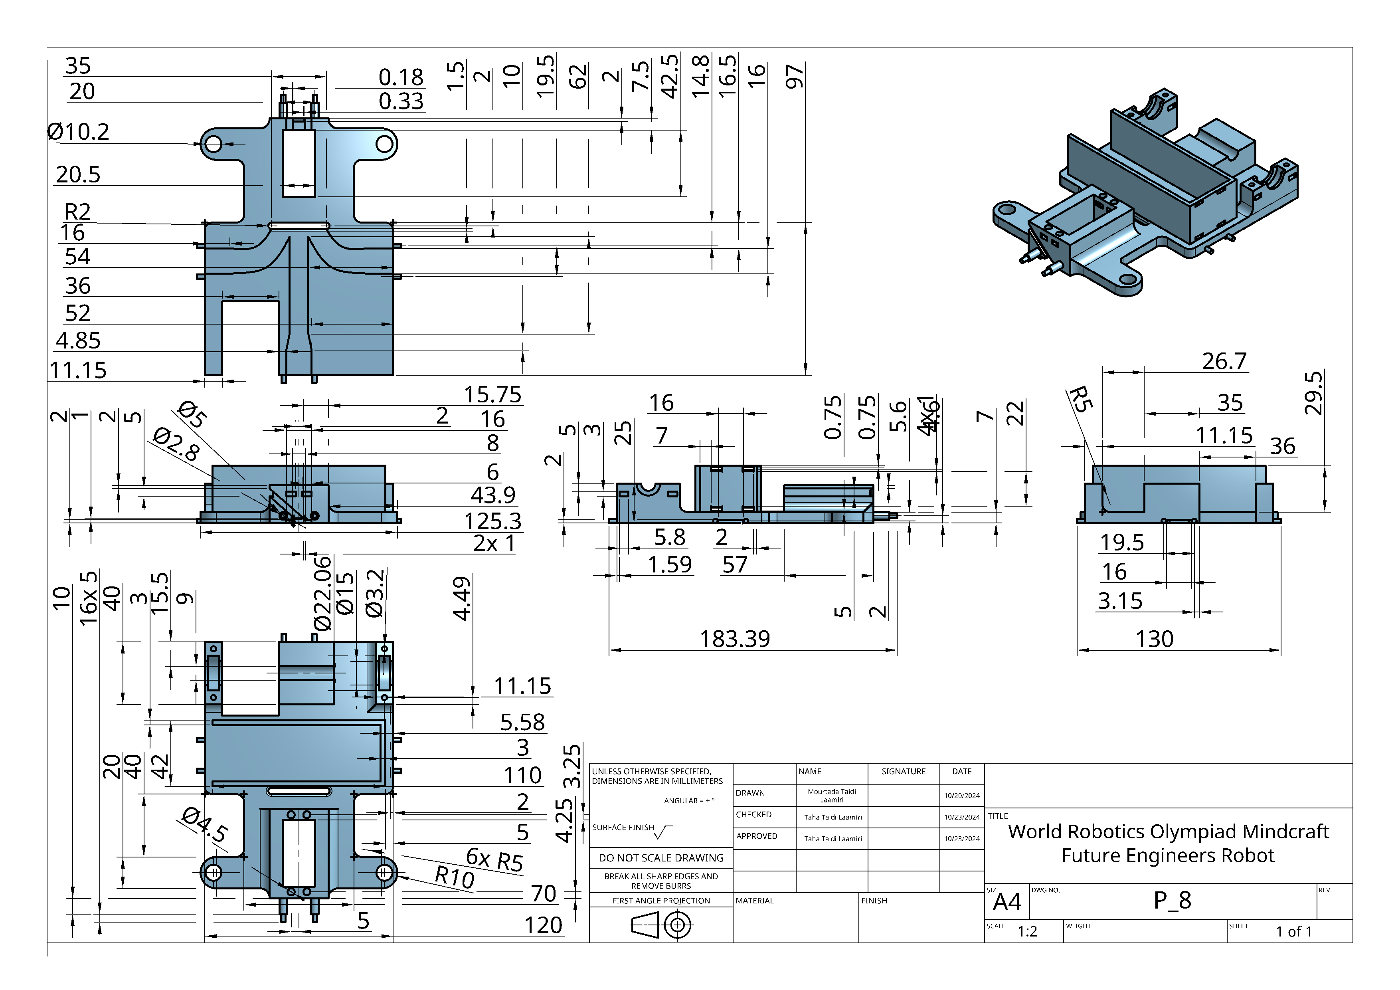
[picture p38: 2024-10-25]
Models/ Parts/0x00-Robot Base/Drawing Robot Base (1).png

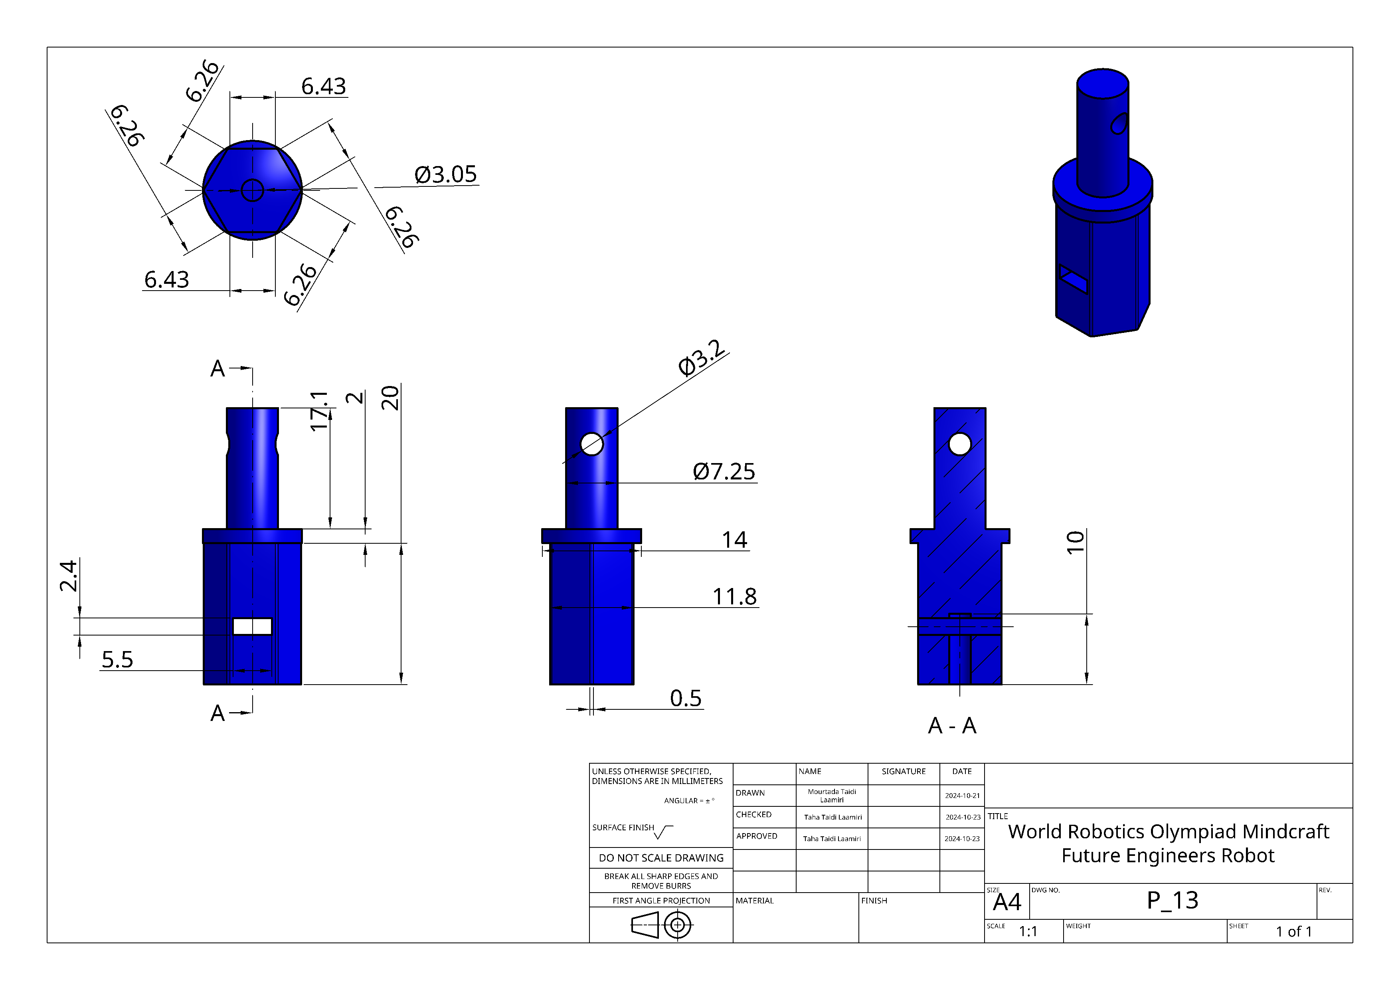
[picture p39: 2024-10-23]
Models/ Parts/0x05-Front Short Shaft/Drawing Front Short Shaft.png

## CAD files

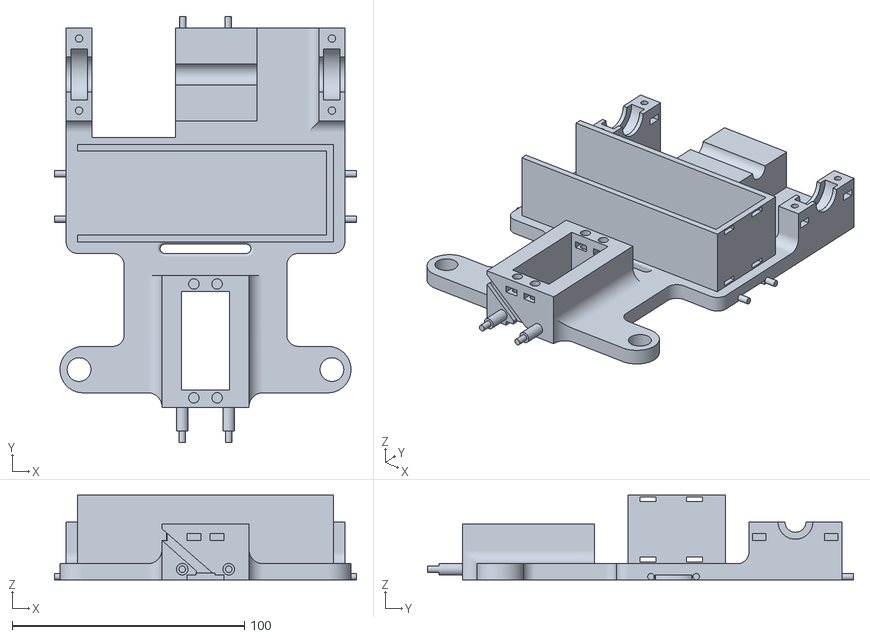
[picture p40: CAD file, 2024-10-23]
Models/ Parts/0x00-Robot Base/Robot Base .stl
130.0 x 183.4 x 36.5

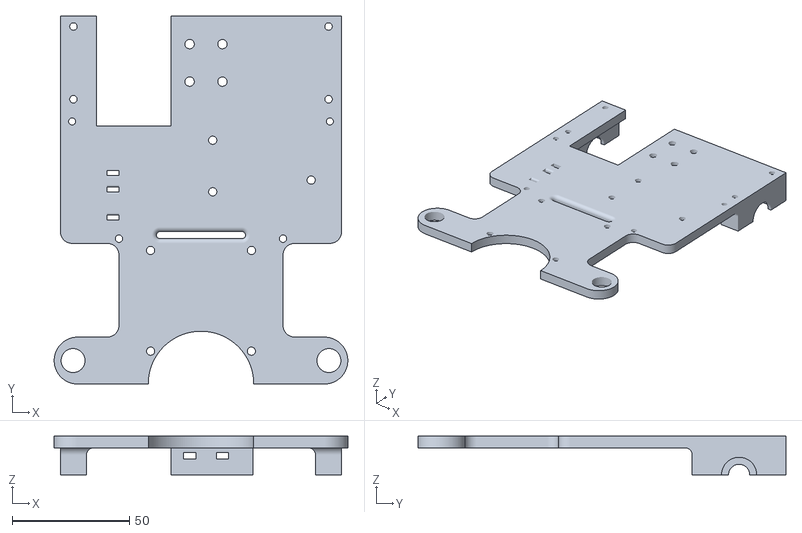
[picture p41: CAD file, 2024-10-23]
Models/ Parts/0x01-Second Layer/Second Layer.stl
125.3 x 157.0 x 16.5

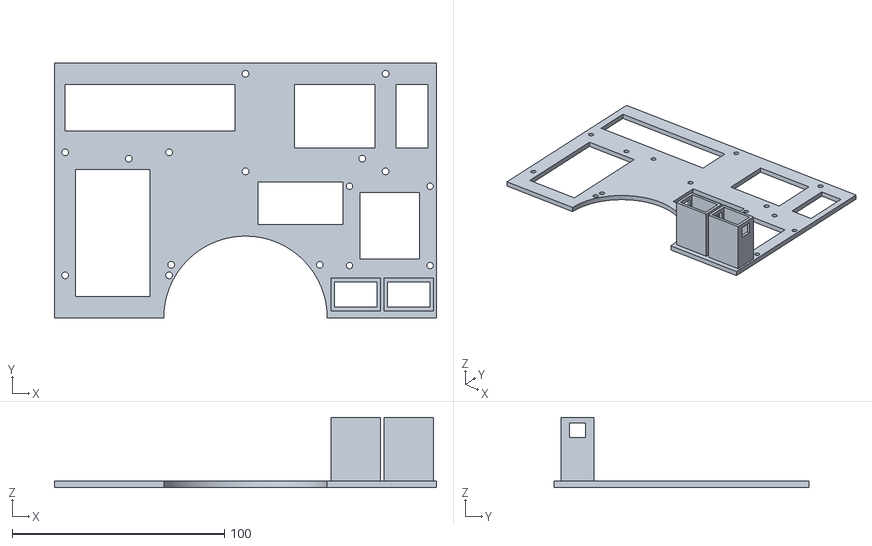
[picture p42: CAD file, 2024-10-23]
Models/ Parts/0x02-Third Layer/Third Layer.stl
180.0 x 120.0 x 33.0

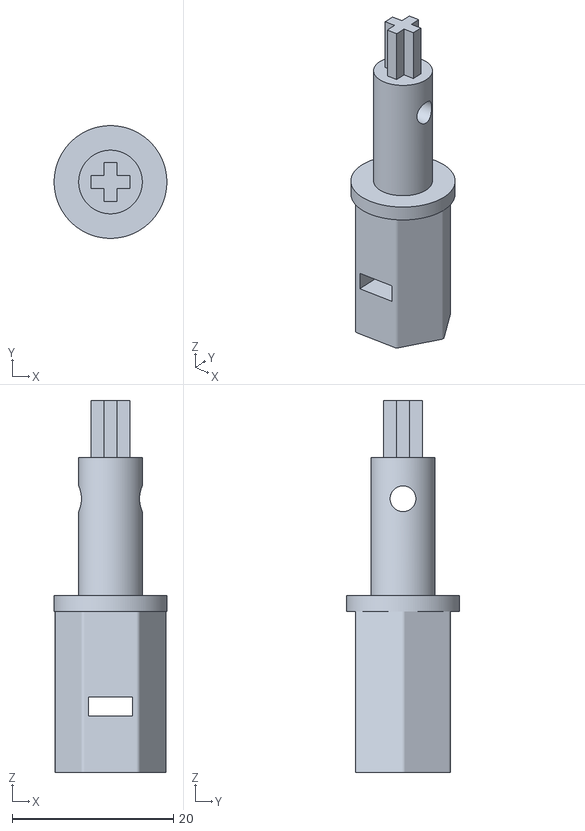
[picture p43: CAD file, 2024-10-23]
Models/ Parts/0x03-Short Shaft/Short Shaft.stl
14.0 x 14.0 x 46.2

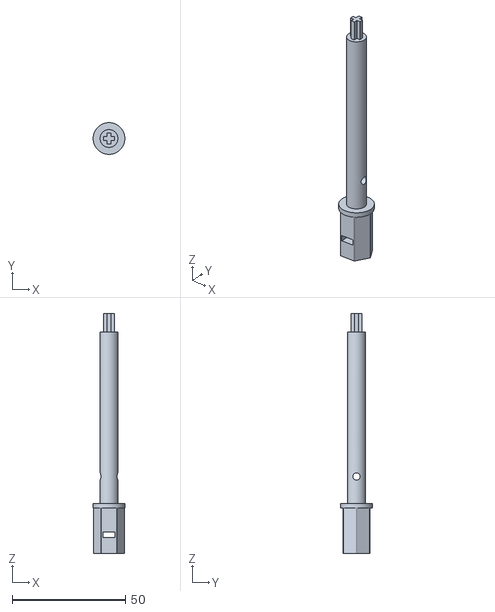
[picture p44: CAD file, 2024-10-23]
Models/ Parts/0x04-Long Shaft/Long Shaft.stl
14.0 x 14.0 x 105.9

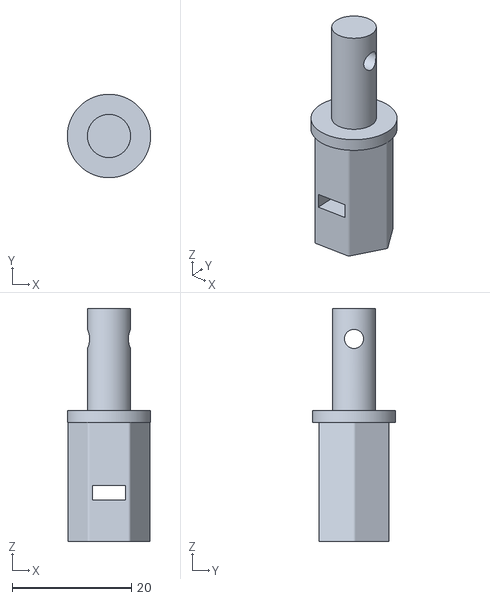
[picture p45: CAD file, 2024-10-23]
Models/ Parts/0x05-Front Short Shaft/Front Short Shaft.stl
14.0 x 14.0 x 39.1

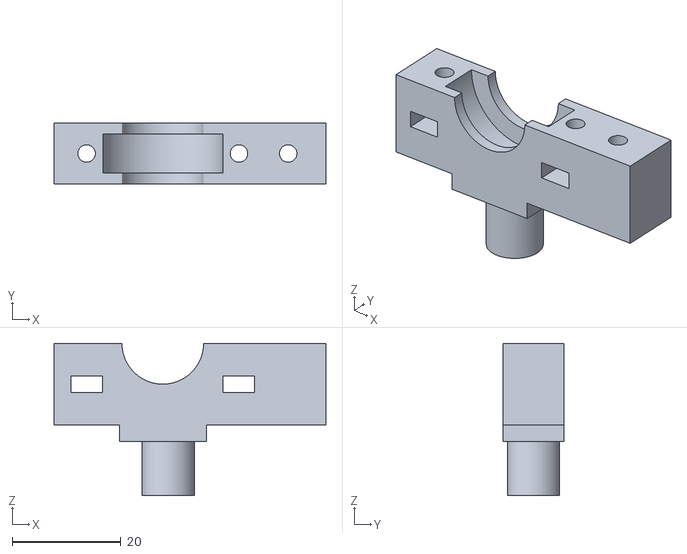
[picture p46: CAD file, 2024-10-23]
Models/ Parts/0x06-Berring Support Front Bottom/Berring Support Front Bottom.stl
50.0 x 11.1 x 28.0

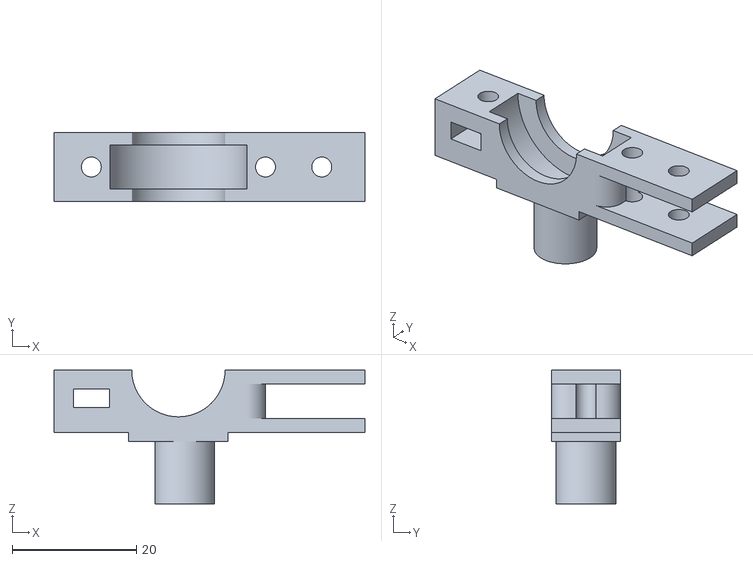
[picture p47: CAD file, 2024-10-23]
Models/ Parts/0x07-Berring Support Front Top/Berring Support Front Top.stl
50.0 x 11.1 x 21.5

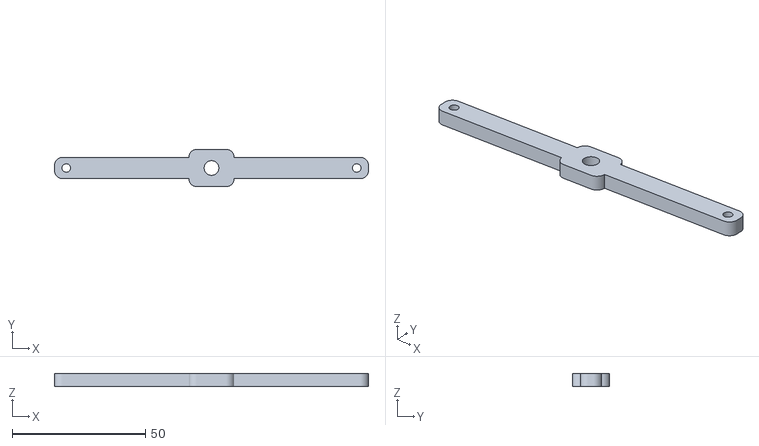
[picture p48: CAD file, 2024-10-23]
Models/ Parts/0x08-Steering Rack/Steering Rack.stl
118.0 x 14.0 x 5.00

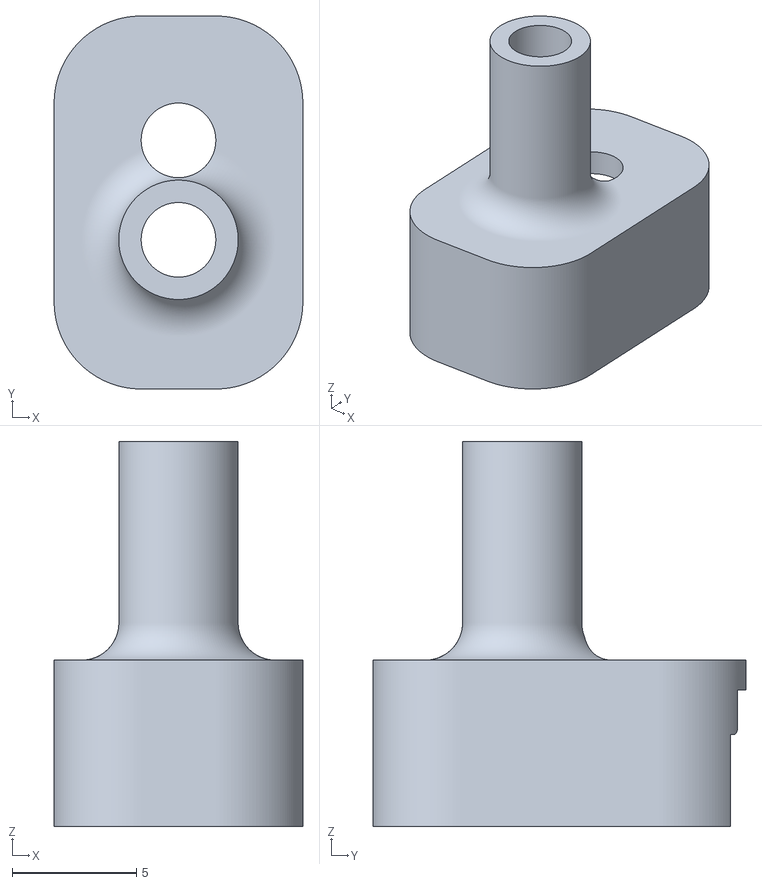
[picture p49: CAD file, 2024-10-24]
Models/ Parts/0x09-Steering Conector/Steering Conector.stl
10.0 x 15.0 x 15.5

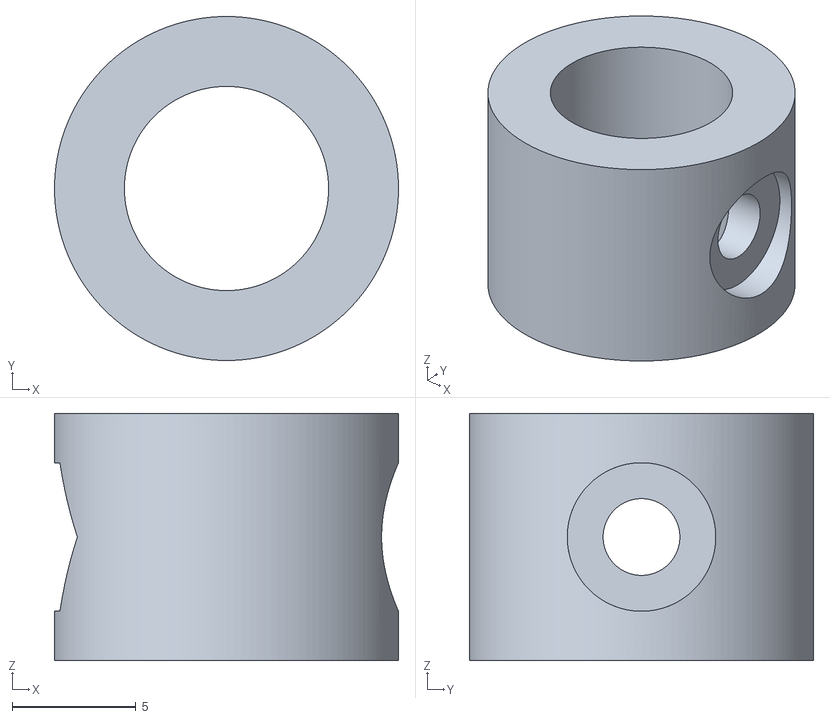
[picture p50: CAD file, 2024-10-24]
Models/ Parts/0x10-Axle Clamp/Axle Clamp.stl
13.9 x 13.9 x 10.0

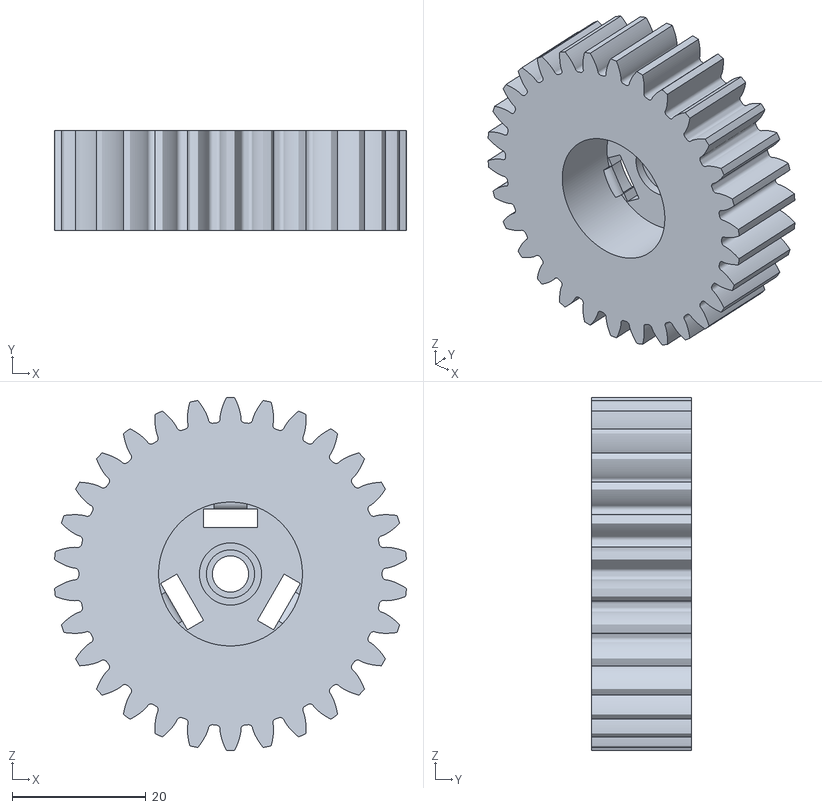
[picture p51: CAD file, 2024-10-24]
Models/ Parts/0x11-Big Gear/Big Gear.stl
52.6 x 15.0 x 52.8

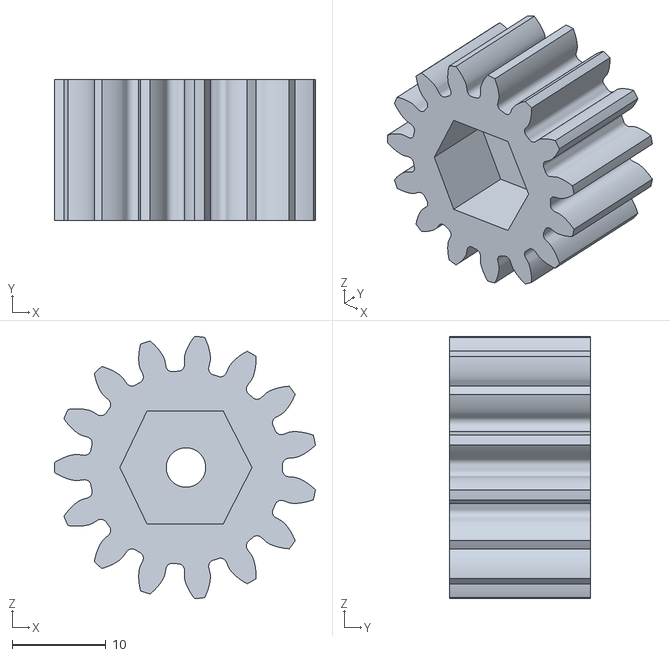
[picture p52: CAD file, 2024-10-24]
Models/ Parts/0x12-Gear/Gear.stl
27.8 x 15.0 x 28.0

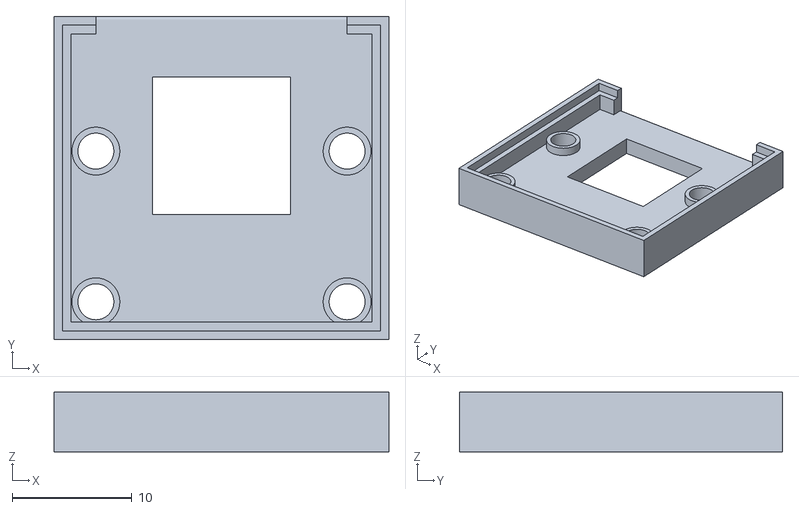
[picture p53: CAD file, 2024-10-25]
Models/ Parts/0x13-Front Support Camera/Front Support Camera.stl
28.0 x 27.0 x 5.00

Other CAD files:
Models/ Parts/0x14-Back Support Camera/Back Support Camera.stl
Models/ Parts/0x15-Conector Support Camera/Conector Support Camera.stl

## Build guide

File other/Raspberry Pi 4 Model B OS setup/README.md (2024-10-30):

= Setting Up Your Raspberry Pi

== Getting Started with Your Raspberry Pi

image::https://img.youtube.com/vi/CQtliTJ41ZE/0.jpg[youtube, link="https://www.youtube.com/watch?v=CQtliTJ41ZE"]

To get started with your Raspberry Pi, you'll need the following:

* a xref:raspberry-pi.adoc#power-supply[power supply]
* boot media (e.g., a xref:getting-started.adoc#recommended-sd-cards[microSD card with ample storage and speed])

You can set up your Raspberry Pi as an interactive computer with a desktop or as a _headless_ computer accessible only over the network. To set up headlessly, preconfigure a hostname, user account, network connection, and SSH when installing the operating system.

For a direct setup, you’ll need:

* Display
* Cable to connect your Raspberry Pi to your display
* Keyboard
* Mouse

== Power Supply

Here’s the required USB-PD power mode for various Raspberry Pi models:

[%header,cols="1,1,1"]
|===
|Model
|Recommended Power Supply (voltage/current)
|Raspberry Pi Power Supply Link

|Raspberry Pi 5
|5V/5A, 5V/3A limits peripherals to 600mA
|https://www.raspberrypi.com/products/27w-power-supply/[27W USB-C power supply]

|Raspberry Pi 4 Model B
|5V/3A
|https://www.raspberrypi.com/products/type-c-power-supply/[15W USB-C power supply]

|Raspberry Pi 3 (all models)
|5V/2.5A
|https://www.raspberrypi.com/products/micro-usb-power-supply/[12.5W Micro USB power supply]

|Raspberry Pi 2 (all models)
|5V/2.5A
|https://www.raspberrypi.com/products/micro-usb-power-supply/[12.5W Micro USB power supply]

|Raspberry Pi 1 (all models)
|5V/2.5A
|https://www.raspberrypi.com/products/micro-usb-power-supply/[12.5W Micro USB power supply]

|Raspberry Pi Zero (all models)
|5V/2.5A
|https://www.raspberrypi.com/products/micro-usb-power-supply/[12.5W Micro USB power supply]
|===

image::images/peripherals/cable-power.png[alt="Plugging a power supply into a Raspberry Pi"]

Plug the power supply into the port marked "POWER IN," "PWR IN," or "PWR". Be careful to use the correct port, as some models have output USB ports similar to the power port.

== Boot Media

Raspberry Pi models require external storage, typically a microSD card. Only recent models support booting from USB or network storage.

image::images/peripherals/sd-card.png[alt="Inserting a microSD card into a Raspberry Pi"]

Recommended SD cards:

* Minimum 32GB for Raspberry Pi OS installations
* Minimum 16GB for Raspberry Pi OS Lite installations
* Up to 2TB (MBR limit)

Older models and specific ones like Raspberry Pi Zero support only up to 256GB boot partitions.

== Keyboard and Mouse

You can use any USB port for connecting a wired keyboard and mouse or a USB Bluetooth receiver.

image:images/peripherals/cable-key.png[alt="Plugging a keyboard into a Raspberry Pi"]
image:images/peripherals/cable-mouse.png[alt="Plugging a mouse into a Raspberry Pi"]

== Display Connectivity

[%header,cols="1,1"]
|===
|Model
|Display Outputs

|Raspberry Pi 5
|2× micro HDMI

|Raspberry Pi 4 (all models)
|2× micro HDMI, audio and composite out via TRRS jack

|Raspberry Pi 3 (all models)
|HDMI, audio and composite out via TRRS jack

|Raspberry Pi 2 (all models)
|HDMI, audio and composite out via TRRS jack

|Raspberry Pi 1 Model B+ / Model A+
|HDMI, audio and composite out via TRRS jack

|Raspberry Pi Zero (all models)
|mini HDMI
|===

Use `HDMI0` for the primary display if your model has multiple HDMI ports. 

== Audio Support

All Raspberry Pi models with HDMI, micro HDMI, or mini HDMI support audio over HDMI. Models with Bluetooth also support Bluetooth audio, and models with a 3.5mm auxiliary jack (TRRS) support audio output (amplification may be needed).

== Networking

Models with Wi-Fi and Bluetooth:

* Raspberry Pi 5
* Raspberry Pi 4
* Raspberry Pi 3B+ / 3
* Raspberry Pi Zero W / Zero 2 W

For models without Ethernet, use a USB-to-Ethernet adapter.

image::images/peripherals/cable-net.png[alt="Plugging an Ethernet cable into a Raspberry Pi"]

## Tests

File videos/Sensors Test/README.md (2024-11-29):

## Sensors Testing

---

### Temperature sensor testing
https://youtu.be/fO5gJq1IJq0

---

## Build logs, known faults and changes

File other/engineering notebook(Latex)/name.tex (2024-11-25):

\documentclass[12pt,a4paper]{article}
\usepackage[utf8]{inputenc}
\usepackage[T1]{fontenc}
\usepackage{graphicx}
\usepackage{amsmath}
\usepackage{amssymb}
\usepackage{hyperref}
\usepackage{geometry}
\usepackage{fancyhdr} % For headers and footers
\usepackage{qrcode}
\usepackage{array}
\usepackage{tabularx}
\usepackage{float}
\restylefloat{figure}

\geometry{margin=1in}

\title{\vspace{-2cm} % Adjusts vertical spacing
     \\ % Adds logo
    \vspace{2cm}
    Future Engineers WRO 2024 \\ \textbf{Mindcraft International Team Documentation}
}
\author{Team Members: Taha Taidi Laamiri, Salmane Derdeb \\ and Mortada Taidi Laamiri \\ Supervising Mentor: Soufiane ElHatri}
\date{\today}

\begin{document}

\maketitle

\begin{abstract}
This document provides a comprehensive overview of the design, development, and testing of our robot for the Future Engineers WRO 2024 competition. The project integrates advanced robotics concepts, innovative engineering solutions, and sustainable design practices. It details our work in hardware construction, software programming, testing, and refinement, providing an in-depth look at the Mindcraft International Team's approach and achievements.
\end{abstract}

\newpage
\tableofcontents

% Header and footer configuration
\pagestyle{fancy}
\fancyhf{}
\fancyhead[L]{Future Engineers WRO 2024 - Mindcraft International Team}
\fancyhead[R]{\thepage}
\newpage

\section{Introduction}
The Future Engineers WRO 2024 competition encourages teams to create innovative robots addressing real-world challenges through sustainable engineering and advanced technologies. The Mindcraft International Team has focused on developing an autonomous robot optimized for efficiency and reliability while adhering to the competition's sustainable development goals.

This documentation outlines our journey, from brainstorming and conceptualization to testing and final implementation. The robot was designed to navigate a complex track, detect objects, and make autonomous decisions, leveraging tools like the Raspberry Pi 4 Model B, ROS2 Humble, and custom CNC-machined parts.

Key objectives:
\begin{itemize}
    \item Develop a reliable, autonomous robot using affordable and sustainable materials.
    \item Implement modular, reusable components for easy adaptability and repair.
    \item Optimize software algorithms to ensure real-time processing and precise navigation.
    \item Integrate cutting-edge AI techniques for obstacle detection and path planning.
\end{itemize}

\newpage

\section{Team member}
Our team consists of three highly motivated and skilled individuals:
\begin{itemize}
    \item Taha TAIDI LAAMIRI
    \item Salmane DERDEB
    \item Mortada TAIDI LAAMIRI
\end{itemize}
Each member brings unique strengths and expertise, contributing to the success of the Mindcraft International Team in the Future Engineers WRO 2024 competition.

\begin{figure}[H]
    \centering
    
    \caption{From left to right: Mortada, Taha and Salmane.}

\end{figure}

\newpage

\section{Design Considerations Before CAD Modeling}
Before beginning the CAD modeling process, we outlined key requirements to ensure our robot was compact, efficient, and optimized for competition challenges.

\subsection{Key Requirements}
\begin{itemize}
    \item \textbf{Compact Size}: Fit within a 20cm cube for optimal navigation.
    \item \textbf{Turning Radius}: Achieve a maximum outside turning circle of 40cm.
    \item \textbf{Stability}: Maintain a low center of gravity for balanced movement.
    \item \textbf{Weight Distribution}: Ensure equal weight distribution to prevent tipping.
    \item \textbf{High Traction}: Use high-friction wheels for better control.
    \item \textbf{Modular Assembly}: Assemble parts with screws, nuts, and zip ties—no glue.
    \item \textbf{Lightweight Design}: Reduce weight for better speed and efficiency.
    \item \textbf{Differential System}: Allow smooth and efficient turning.
    \item \textbf{Battery and Component Safety}: Position batteries securely and protect components.
    \item \textbf{Ease of Reassembly}: Design parts for easy and error-free reassembly.
\end{itemize}

\subsection{Study and Planning}
The design was meticulously planned to prioritize compactness, stability, and ease of modification. Using readily available parts ensured accessibility and reproducibility for other teams.
\newpage
\section{Initial Robot Design and Iterations}

\begin{figure}
    \centering
    
    \caption{LEGO robot used in the national competition.}

\end{figure}
\subsection{National Competition: LEGO Robot}
Our initial robot, built with LEGO components, was easy to construct but faced several limitations:
\begin{itemize}
    \item \textbf{Size and Speed Issues}: The robot was too large and slow for the competition.
    \item \textbf{Obstacle Challenges}: Difficulty in completing obstacle and parking tasks.
    \item \textbf{Structural Weaknesses}: LEGO components lacked the sturdiness needed for advanced tasks.
\end{itemize}

\subsection{First Version: Oversized DIY Robot}
After qualifying for the international stage, we decided to build a 100\% DIY robot, making all the mechanics and body ourselves while purchasing only the electronics. The first version was oversized and heavy, impacting speed and maneuverability.

\subsection{Second Version: Lack of Differential System}
In the second iteration of our DIY robot, we reduced the size and weight but encountered new challenges:
\begin{itemize}
    \item \textbf{No Differential System}: Turning was inefficient, requiring a 150cm radius to complete a full turn.
    \item \textbf{Inefficient Design}: Poor handling prevented precise movements required for competition.
\end{itemize}

\subsection{Third Version: Final Optimized Robot}
The third version incorporated all lessons learned:
\begin{itemize}
    \item \textbf{Compact Design}: Fits within a 20cm cube.
    \item \textbf{Differential System}: Enabled efficient turning within a 40cm radius.
    \item \textbf{Hardware Upgrade}: Switched to Raspberry Pi 4B for better compatibility, reduced weight, and energy efficiency.
    \item \textbf{Modular Assembly}: Assembled with screws and zip ties for easy modifications.
    \item \textbf{Safety Features}: Secured battery placement and protected components.
\end{itemize}

\begin{figure}[ht]
    \centering
    
    \caption{Final optimized robot design.}
    \label{fig:final_robot}
\end{figure}

\section{3D CAD Modeling}
\subsection{Why We Chose Onshape}
\begin{itemize}
    \item \textbf{Cloud-Based Collaboration}: Allowed team members to work simultaneously from different locations.
    \item \textbf{Free for Educational Use}: Eliminated software costs while providing advanced CAD features.
    \item \textbf{Accessible Anywhere}: Runs in a browser, making it hardware-independent.
    \item \textbf{Powerful CAD Tools}: Provided tools for creating complex mechanical components.
\end{itemize}

\begin{figure}[ht]
    \centering
    
    \caption{Onshape logo.}
    \label{fig:onshape}
\end{figure}

\begin{figure}[ht]
    \centering
    
    \caption{3D model of the robot in Onshape.}
    \label{fig:onshape_model}
\end{figure}

\subsection{CAD Features and Outputs}
The CAD design included:
\begin{itemize}
    \item Steering system linkages for precise control.
    \item Differential gear systems for efficient power transfer.
    \item Custom chassis mounts and supports for modular assembly.
\end{itemize}

\section{3D Printing}
\subsection{Why 3D Printing?}
\begin{itemize}
    \item Enables creation of complex geometries not feasible with other methods.
    \item Supports rapid prototyping for iterative design improvements.
    \item Cost-effective and generates less material waste.
\end{itemize}

\subsection{Creality K1 Max}
We used the Creality K1 Max for its:
\begin{itemize}
    \item \textbf{Large Build Volume}: Allowed printing of large components in a single piece.
    \item \textbf{High Speed}: Enabled fast production of prototypes.
    \item \textbf{Precision}: Ensured parts fit together seamlessly.
\end{itemize}

\begin{figure}[ht]
    \centering
    
    \caption{Creality K11 Max.}
    \label{fig:creality}
\end{figure}

\begin{figure}[ht]
    \centering
    
    \caption{3D printed parts for the robot.}
    \label{fig:printed_parts}
\end{figure}

\section{Robot Parts Details}
The following table lists the robot's custom-designed and printed components:

\begin{table}
    \centering
    \begin{tabular}{|l|l|}
        \hline
        \textbf{Part Name} & \textbf{Description} \\ \hline
        Robot Base & Foundation of the chassis. \\ \hline
        Steering Rack & Enables precise turning control. \\ \hline
        Camera Mount & Holds the vision system securely. \\ \hline
        Differential Gears & Transmits power efficiently to wheels. \\ \hline
        Motor Mount & Secures the motors in place. \\ \hline
    \end{tabular}
    \caption{List of key robot components.}
    \label{tab:robot_parts}
\end{table}

\newpage

\section*{Bill of Materials}

\renewcommand{\arraystretch}{1.5} % Adjust row height for readability

\setlength{\extrarowheight}{2pt}  % Additional row spacing

\begin{tabularx}{\textwidth}{|l|X|X|X|}
\hline
\textbf{Code} & \textbf{Name} & \textbf{Description} & \textbf{Image} \\
\hline
0x00 & Raspberry Pi 4B & Main computing unit & 
 \\
\hline
0x01 & Arduino Nano & Microcontroller & 
 \\
\hline

\end{tabularx}

\newpage

\section*{}

\begin{tabularx}{\textwidth}{|l|X|X|X|}
\hline
0x02 & RPLidar C1 & LiDAR sensor for object detection & 
 \\
\hline
0x03 & VL53L1X Sensor & Time-of-flight distance sensor & 
 \\
\hline
0x04 & Gyroscope Sensor & Measures angular velocity & 
 \\
\hline
0x05 & Raspberry Pi Camera Module 3 Wide & Captures video for color detection & 
 \\
\hline
0x06 & DC Brushed Motor with Encoder & Motor for movement with encoder feedback & 
 \\
\hline
0x07 & Wheels & Wheels for robot movement & 
 \\
\hline
0x08 & L298 Motor Driver & Command Motor High Voltage with logic voltage 5v & 
 \\
\hline

\end{tabularx}

\newpage

\section*{}

\begin{tabularx}{\textwidth}{|l|X|X|X|}

\hline

0x09 & Servo motor Metal Gear Box 180° & For Robot turning & 
 \\
\hline
0x10 & 5V Power Converter & 5V Power Converter & 
 \\
\hline
0x11 & 5V Lipo 3S 2200mah 11.1V 50C & Lithium Polymer Battery & 
 \\
\hline
0x12 & IMAX B6AC V2 & Battery Charger & 
 \\
\hline
0x13 & 7806 Transistor & 6V Voltage Regulator & 
 \\
\hline
0x14 & Switch High Amper & High Current Switch & 
 \\
\hline
0x15 & 	Buzzer Alarm Batterie Lipo & Lipo Battery Alarm	 & 
 \\
\hline

0x16 & Servo Tester & Servo Motor Tester & 
 \\
\hline
0x17 & 	Servobras & Servo Arm & 
 \\
\hline
\end{tabularx}

\newpage

\section*{}

\begin{tabularx}{\textwidth}{|l|X|X|X|}
\hline
0x18 & SD Card 64GB & 64GB SD Card & 
 \\
\hline
\end{tabularx}

\begin{figure}[H]
    \centering
    \caption{List of materials (BOM List)}
    \label{fig:bom}
\end{figure}

\newpage

\begin{figure}[H]
    \vspace{4cm}
    \centering
    
    \caption{Robot Views}
\end{figure}

\begin{figure}[H]
    \vspace{4cm}
    \centering
    
    \caption{Assembly Power}
\end{figure}

\begin{figure}[H]
    \vspace{4cm}
    \centering
    
    \caption{Assembly Power Animation}
\end{figure}

\begin{figure}[H]
    \vspace{4cm}
    \centering
    
    \caption{Assembly Steering}
\end{figure}

\begin{figure}[H]
    \vspace{4cm}
    \centering
    
    \caption{Assembly Steering Animation}
\end{figure}

\begin{figure}[H]
    \vspace{4cm}
    \centering
    
    \caption{Robot Base}
\end{figure}

\begin{figure}[H]
    \vspace{4cm}
    \centering
    
    \caption{Second Layer}
\end{figure}

\begin{figure}[H]
    \vspace{4cm}
    \centering
    
    \caption{Third Layer}
\end{figure}

\begin{figure}[H]
    \vspace{4cm}
    \centering
    
    \caption{Short Shaft}
\end{figure}

\begin{figure}[H]
    \vspace{4cm}
    \centering
    
    \caption{Long Shaft}
\end{figure}

\begin{figure}[H]
    \vspace{4cm}
    \centering
    
    \caption{Front Short Shaft}
\end{figure}

\begin{figure}[H]
    \vspace{4cm}
    \centering
    
    \caption{Berring Support Front Bottom}
\end{figure}

\begin{figure}[H]
    \vspace{4cm}
    \centering
    
    \caption{Berring Support Front Top}
\end{figure}

\begin{figure}[H]
    \vspace{4cm}
    \centering
    
    \caption{Steering Rack}
\end{figure}

\begin{figure}[H]
    \vspace{4cm}
    \centering
    
    \caption{Steering Conector}
\end{figure}

\begin{figure}[H]
    \vspace{4cm}
    \centering
    
    \caption{Axle Clamp}
\end{figure}

\begin{figure}[H]
    \vspace{4cm}
    \centering
    
    \caption{Big Gear}
\end{figure}

\begin{figure}[H]
    \vspace{4cm}
    \centering
    
    \caption{Gear}
\end{figure}

\begin{figure}[H]
    \vspace{4cm}
    \centering
    
    \caption{Front Support Camera}
\end{figure}

\begin{figure}[H]
    \vspace{4cm}
    \centering
    
    \caption{Back Support Camera}
\end{figure}

\begin{figure}[H]
    \vspace{4cm}
    \centering
    
    \caption{Conector Support Camera}
\end{figure}

\newpage

\section{Electrical Components and Integration}
The robot's electrical system comprises various components working together to achieve efficient and autonomous operation. This section describes the purpose and role of each electrical part, along with its integration into the overall design.

\subsection{Schemes}
\begin{figure}[H]
    \centering
    
    \caption{Electrical Diagram}
    \label{fig:scheme}
\end{figure}

\subsection{Raspberry Pi 4B}
\begin{itemize}
    \item \textbf{Purpose}: The Raspberry Pi 4B serves as the central processing unit (CPU) for the robot, running the control algorithms, ROS2 Humble, and real-time data processing from sensors.
    \item \textbf{Specifications}: Quad-core Cortex-A72, 8GB RAM, USB 3.0 ports, and micro-HDMI output.
    \item \textbf{Integration}: It interfaces with sensors, motor drivers, and peripherals via GPIO, I2C, and USB ports, providing the computational power for vision and navigation.
\end{itemize}
\newpage

\subsection{RPLIDAR C1 (LIDAR Sensor)}
\begin{itemize}
    \item \textbf{Purpose}: The LIDAR sensor is used for mapping the environment, detecting obstacles, and enabling precise navigation through SLAM (Simultaneous Localization and Mapping).
    \item \textbf{Specifications}: 360-degree scanning range, up to 8m distance, 8000 samples per second.
    \item \textbf{Integration}: Connected to the Raspberry Pi via USB, the data is processed using ROS2 packages for real-time mapping and obstacle detection.
\end{itemize}

\subsection{Arduino Nano}
\begin{itemize}
    \item \textbf{Purpose}: The Arduino Nano acts as a secondary microcontroller for handling low-level tasks such as motor control and sensor data acquisition.
    \item \textbf{Specifications}: ATmega328P microcontroller, 14 digital I/O pins, and I2C compatibility.
    \item \textbf{Integration}: Communicates with the Raspberry Pi over I2C, relaying data from sensors like the MPU6050 and VL53L0X DTOF sensors.
\end{itemize}

\subsection{VL53L0X DTOF Sensors (x4)}
\begin{itemize}
    \item \textbf{Purpose}: These sensors measure distances to obstacles with high precision, providing data for collision avoidance and path correction.
    \item \textbf{Specifications}: Measurement range of up to 2m, high-accuracy Time-of-Flight technology.
    \item \textbf{Integration}: Positioned on each side of the robot, connected via I2C, and managed by the Arduino Nano for fast response times.
\end{itemize}

\subsection{MPU6050 (Gyroscope and Accelerometer)}
\begin{itemize}
    \item \textbf{Purpose}: The MPU6050 provides orientation and motion data, critical for maintaining stability and correcting drift.
    \item \textbf{Specifications}: 3-axis gyroscope and 3-axis accelerometer.
    \item \textbf{Integration}: Data is processed by the Arduino Nano and sent to the Raspberry Pi for real-time corrections.
\end{itemize}

\subsection{Pi Camera (PiCam V2)}
\begin{itemize}
    \item \textbf{Purpose}: Captures video feed for lane detection, cube identification, and object tracking.
    \item \textbf{Specifications}: 8MP resolution, 1080p video recording.
    \item \textbf{Integration}: Mounted on a 3D-printed bracket, the camera interfaces directly with the Raspberry Pi for real-time image processing.
\end{itemize}

\subsection{Motor Driver (L298N) and Motors}
\begin{itemize}
    \item \textbf{Purpose}: Controls the robot’s four-wheel drive system, enabling forward, backward, and differential motion.
    \item \textbf{Specifications}: Dual H-bridge motor driver with PWM support.
    \item \textbf{Integration}: Receives PWM signals from the Arduino Nano and drives the DC motors.
\end{itemize}

\subsection{Battery and Power Management}
\begin{itemize}
    \item \textbf{Purpose}: Provides power to all components, including the Raspberry Pi, sensors, and motors.
    \item \textbf{Specifications}: 12V 5000mAh LiPo battery.
    \item \textbf{Integration}: Managed through a custom power distribution board with safety fuses and voltage regulators.
\end{itemize}

\newpage

\section{Software and Coding}
The software infrastructure is built on ROS2 Humble, leveraging various libraries and tools for real-time robot operation.

\subsection{ROS2 Humble}
\begin{itemize}
    \item \textbf{Purpose}: Provides a modular framework for robotics applications, handling sensor integration, navigation, and control.
    \item \textbf{Features Used}:
    \begin{itemize}
        \item Navigation2: Path planning and obstacle avoidance.
        \item Sensor Fusion: Integrates LIDAR, camera, and DTOF data.
        \item RCLPy: Python-based ROS client library for custom scripts.
    \end{itemize}
\end{itemize}

\begin{figure}[ht]
    \centering
    
    \caption{ROS2 Logo.}
    \label{fig:ros2}
\end{figure}

\subsection{RPLIDAR C1 Integration}
\begin{itemize}
    \item \textbf{Purpose}: Enables SLAM for environment mapping and obstacle detection.
    \item \textbf{Implementation}: The LIDAR data is processed using the ROS2 slam toolbox package, creating a dynamic map of the environment.
\end{itemize}

\begin{figure}[H]
    \centering
    
    \caption{Rplidar Visualization using rviz2}
    \label{fig:rviz2}
\end{figure}

\subsection{Pi Camera (PiCam V2) and OpenCV}
\begin{itemize}
    \item \textbf{Purpose}: Used for visual processing tasks, including lane detection and object recognition.
    \item \textbf{Implementation}: OpenCV handles image preprocessing, edge detection, and color filtering, integrated with ROS2 nodes for real-time control.
\end{itemize}

\subsection{Dashboard}
\begin{itemize}
    \item \textbf{Purpose}: Provides a live interface for monitoring robot performance and issuing commands.
    \item \textbf{Tools Used}: Tkinter framework for the backend, integrated with ROS2.
    \item \textbf{Features}: Real-time sensor data visualization, camera feed display, and remote control options.
\end{itemize}

\newpage

\section{Strategy and Autonomous Behavior}
The robot's strategy focuses on efficient pathfinding, obstacle avoidance, and task completion.

\subsection{Pathfinding and Navigation}
The robot uses data from LIDAR and DTOF sensors for precise navigation. SLAM enables it to dynamically map the course, ensuring efficient path selection.

\subsection{Obstacle Avoidance}
Sensors like LIDAR, DTOF, and the Pi Camera work together to identify and avoid obstacles. A layered costmap from ROS2 Navigation2 ensures safe paths are planned in real-time.

\subsection{Task-Specific Behaviors}
\begin{itemize}
    \item **Cube Identification**: The robot identifies cubes using the Pi Camera and avoids them during navigation.
    \item **Lane Following**: OpenCV processes the camera feed to detect and follow lanes on the track.
    \item **Dynamic Adjustments**: The robot adjusts speed and direction based on sensor feedback, ensuring smooth operation.
\end{itemize}

\begin{figure}
    \centering
    
    \caption{Open Challenge Strategy.}
    \label{fig:open}
\end{figure}

\newpage

\begin{figure}
    \centering
    
    \caption{Obstacle Challenge Strategy.}
    \label{fig:obstacle}
\end{figure}

\newpage

\subsection{Randomizer & Score Calculator}
\begin{itemize}
    \item \textbf{Purpose}: Offering an online open-source website that randomizes the map and calculates the score.
    \item \textbf{Implementation}: Using HTML, CSS for forend, and JavaScript for Backend.
    \item \textbf{Using}: Used Github Pages to build and upload the website.
\end{itemize}

\begin{figure}[ht]
    \centering
    
    \caption{Part of JavaScript Code.}
    \label{fig:JS}
\end{figure}

\newpage

\section{Links}

\subsection{Youtube Channel}
\vspace{0.5cm}
\qrcode[height=4cm]{https://www.youtube.com/@MindcraftWRO-kw8vp}
\vspace{1cm}

\subsection{Github Repository}
\vspace{0.5cm}
\qrcode[height=4cm]{https://github.com/DexterTaha/WRO-FE-2024-Mindcraft-International}
\vspace{1cm}

\subsection{Onshape Link}
\vspace{0.5cm}
\qrcode[height=4cm]{https://cad.onshape.com/documents/1c6f1405e84d0c390333223c/w/c90b719cdc670bdbfb16a84e/e/3d798daea79d75d88b470c18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}

\newpage
\end{document}

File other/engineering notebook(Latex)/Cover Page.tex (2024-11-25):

%%%%%%%%%%%%%%%%%%%%%%%%%%%%%%%%%%%%%%%%%%%%%%%%%%%%%%%%%%%%%%%%%%%%%%%%%%%%%%%%%%%%
%%----------------------------------------------------------------------------------
% DO NOT Change this is the required setting A4 page, 11pt, onside print, book style
%%----------------------------------------------------------------------------------
\documentclass[a4paper,11pt,oneside]{book} 
\usepackage{MINDCRAFT FE Report} % DO NOT REMOVE THIS LINE. 
%%%%%%%%%%%%%%%%%%%%%%%%%%%%%%%%%%%%%%%%%%%%%%%%%%%%%%%%%%%%%%%%%%%%%%%%%%%%%%%%%%%%

%%%%%%%%%%%%%%%%%%%%%%%%%%%%%%%%%%%%%%%%%%%%%%%%%%%%%%%%%%%%%%%%%%%%%%%%%%%%%%%%%%%%
\begin{document}

    \captionsetup[figure]{margin=1.5cm,font=small,name={Figure},labelsep=colon}
    \captionsetup[table]{margin=1.5cm,font=small,name={Table},labelsep=colon}
    
    \frontmatter
    
    %%%%%%%%%%%%%%%%%%%%%%%%%%%%%%%%%%%%%%%%%%%%%%%%%%%%%%%%%%%%%%%%%%%%%%%%%%%%%%%%
    \begin{titlepage}      
        \begin{center}
            \\[1.5cm]            {\LARGE Mindcraft Team\\[0.5cm]
            WRO Future Engineers Competition}\\[2cm]
			%{\color{blue} \rule{\textwidth}{1pt}}
			
			% -------------------------------
			% You need to edit some details here
			% -------------------------------  
            \linespread{1.2}\huge {
                %%%%%%%%%%%%%%%%%%%%%%%%%%%%
                %TODO: 1 TITLE of Your PROJECT 
                %%%%%%%%%%%%%%%%%%%%%%%%%%%%
                % change the following line                
                Optimized Robotic Object Detection and Localization for WRO Future Engineers
            
            }
            \linespread{1}~\\[2cm]
			%{\color{blue} \rule{\textwidth}{1pt}}
            {\Large 
                %%%%%%%%%%%%%%%%%%%%%%%%%%%%
                %TODO: 2 YOUR NAME
                %%%%%%%%%%%%%%%%%%%%%%%%%%%%             
                % change the following line
                Mindcraft Team
                % change end             
            }\\[1cm] 

            {\large 
                %%%%%%%%%%%%%%%%%%%%%%%%%%%%
                %TODO: 3 YOUR NAME Supervisor's name(s)
                %%%%%%%%%%%%%%%%%%%%%%%%%%%%             
                % change the following line                
                \emph{Team Coach:} Soufiane ELHATRI}\\[1cm] % if applicable
            
    		% PLEASE DO NOT CHANGE THIS TEXT %
            \large Taha TAIDI LAAMIRI\\Salmane DERDEB\\Mortada TAIDI LAAMIRI\\
            %%%
            %TODO:  verify your degree name
            %Master of Science 
            %% 
            %TODO:  verify your degree in
            %in \textit{Data Science and Advanced Computing}\\[0.3cm] 
            \vfill

            \today % Please update this date you can use \date{April 2020} for fixed date
        \end{center}
    \end{titlepage}

    % -------------------------------------------------------------------
    % Declaration
    % -------------------------------------------------------------------
    \newpage
    \thispagestyle{empty}
    \chapter*{\Large Declaration}
    % PLEASE CHANGE THIS TEXT EXCEPT YOUR NAME%
    % -------------------------------
    %TODO: PLEASE ONLY UPDATE HERE -- PLEASE WRITE YOUR NAME %    
    % ------------------------------- 
    I,
    %%%%%%%%%%%%%%%%%%%%%%%
     Firstname(s) Lastname, % Madatory part  TODO
    %%%%%%%%%%%%%%%%%%%%%%%
    of the Department of Computer Science, University of Reading, confirm that this is my own work and figures, tables, equations, code snippets, artworks, and illustrations in this report are original and have not been taken from any other person's work, except where the works of others have been explicitly acknowledged, quoted, and referenced. I understand that if failing to do so will be considered a case of plagiarism. Plagiarism is a form of academic misconduct and will be penalised accordingly. \\
    
    %% Please delete as appropriate. 
    \noindent
    %%%%%%%%%%%%%%%%%%%%%%%%%%%%%%%%%%%%%%%%%%%%%%% 
    %TODO 1 Consent for example copy -  we will use 
    I give consent to a copy of my report being shared with future students as an exemplar. \\
    
    \noindent
    %%%%%%%%%%%%%%%%%%%%%%%%%%%%%%%%%%%%%%%%%%%%%%% 
    %TODO 2 Consent to let the report to use use by library for public use
    I give consent for my work to be made available more widely to members of UoR and public with interest in teaching, learning and research. 
    %%%%%%%%%%%%%%%%%%%%%%%%%%%%%%%%%%%%%%%%%%%%%%%
    ~\\[1cm]
    \begin{flushright}
	%------------------------------ 
	% change the following line
    %TODO: PLEASE UPDATE  Your Name  -------------------------------%
	Firstname(s) Lastname % Please change it to your name
    
    \today
    \end{flushright}

    % -------------------------------------------------------------------
    % Abstract and Acknowledgement
    % -------------------------------------------------------------------
    
    \input{chapters/00_i_abstract}
    % -------------------------------------------------------------------
	% Acknowledgement
	% -------------------------------------------------------------------
   
    \input{chapters/00_ii_acknowledgments}   
    
    % -------------------------------------------------------------------
    % Contents, list of figures, list of tables
    % -------------------------------------------------------------------
    
    \tableofcontents
    \listoffigures
    \listoftables
    \input{glossaries} %  Enter your list of Abbreviation and Symbols in this file

    %%%%%%%%%%%%%%%%%%%%%%%%%%%%%%%%%%%%%%%%%%%%%%%%%%%%%%%%%%%%%%%%%%%%%%%%
    %%                                                                    %%  
    %%  Main chapters and sections of your project                        %%  
    %%  Everything from here on needs updates in your own words and works %%
    %%                                                                    %%
    %%%%%%%%%%%%%%%%%%%%%%%%%%%%%%%%%%%%%%%%%%%%%%%%%%%%%%%%%%%%%%%%%%%%%%%%
    \mainmatter
    % Read for preparation of document in LaTex 
    % Lamport, L. (1986), LATEX: A Document Preparation System, Addison-Wesley.
    
    \input{chapters/01_introduction}
    \input{chapters/02_literature} % https://guides.library.bloomu.edu/litreview
    \input{chapters/03_methodology}
    \input{chapters/04_results}
    \input{chapters/05_discussion}
    \input{chapters/06_conclusions}
    \input{chapters/07_reflection}

    % -------------------------------------------------------------------
    % Bibliography/References  -  Harvard Style was used in this report
    % -------------------------------------------------------------------
    \bibliographystyle{agsm} % Harvard Style 
    
    \bibliography{references}  %  Patashnik, O. (1988), BibTEXing. Documentation for general BibTEX users.
    
    % -------------------------------------------------------------------
    % Appendices
    % -------------------------------------------------------------------
    
    \begin{appendices}
        \input{chapters/appendix_A.tex}
        \input{chapters/appendix_B.tex}
    \end{appendices}
    
\end{document}

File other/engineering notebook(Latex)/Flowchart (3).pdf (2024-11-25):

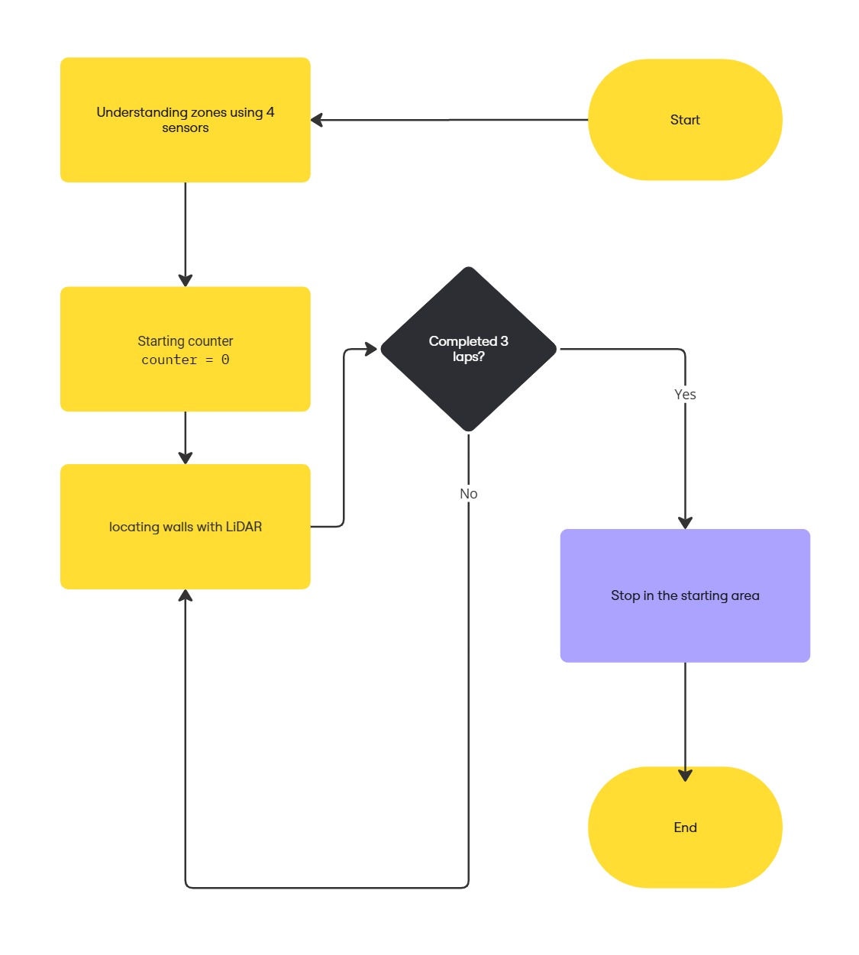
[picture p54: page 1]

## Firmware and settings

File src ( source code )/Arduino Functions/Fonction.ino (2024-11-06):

#include <Servo.h>        // Include the Servo library
#include <VL53L1X.h>      // Include the VL53L1X sensor library
#include <Wire.h>         // Include the Wire library for I2C communication

// Define motors and sensor pins
#define ENA  11                // L298N EN_A motor speed
#define IN_1  13               // L298N in1 motor direction control
#define IN_2  12               // L298N in2 motor direction control
#define buzzerPin  8           // Pin for the buzzer
#define STEERING_SERVO_PIN 10  // Pin connected to the steering servo
#define ENCODER_PIN_A 2        // D2 for encoder
#define ENCODER_PIN_B 3        // D3 for encoder
#define switchPin  A0          // Switch pin

// Define sensor configuration
const uint8_t sensorCount = 4;  // Number of distance sensors
const uint8_t xshutPins[sensorCount] = { 4, 5, 6, 7 };  // XSHUT pins for the VL53L1X sensors

VL53L1X sensors[sensorCount];  // Sensor array

Servo STEERING;  // Create Servo object for steering

// Motor control variables
int MaxSpeed = 255;
int MinSpeed = 127;
int steeringAngle = 0;

volatile long encoderCount = 0;  // Track the encoder pulses
unsigned long lastTime = 0;      // Time for speed calculation
float motorSpeedRPM = 0;         // Motor speed in RPM

// Interrupt Service Routines for Encoder
void encoderISR_A() {
  encoderCount++;  // Increment pulse count on signal change
}
void encoderISR_B() {
  encoderCount--;  // Decrement pulse count on signal change (if using quadrature)
}

// Function to initialize the encoder
void setupEncoder() {
  pinMode(ENCODER_PIN_A, INPUT_PULLUP);  // Set encoder pin A (D2)
  pinMode(ENCODER_PIN_B, INPUT_PULLUP);  // Set encoder pin B (D3)

  attachInterrupt(digitalPinToInterrupt(ENCODER_PIN_A), encoderISR_A, CHANGE);  // Attach interrupt to pin A
  attachInterrupt(digitalPinToInterrupt(ENCODER_PIN_B), encoderISR_B, CHANGE);  // Attach interrupt to pin B
}

// Function to read the current encoder count
long readEncoder() {
  return encoderCount;  // Return the pulse count
}

// Function to reset the encoder count
void resetEncoder() {
  encoderCount = 0;
}

// Function to drive the robot based on distance (in cm) and speed (-100 to 100)
void driveDistanceSpeed(float distanceCM, int speedInput) {
  // Set direction based on distance and speedInput
  if (distanceCM < 0 || speedInput < 0) {
    // Move backward if distance or speed is negative
    digitalWrite(IN_1, LOW);
    digitalWrite(IN_2, HIGH);
    distanceCM = abs(distanceCM);  // Use absolute distance for backward movement
    speedInput = abs(speedInput);  // Use absolute speed for backward movement
  } else {
    // Move forward if distance and speed are positive
    digitalWrite(IN_1, HIGH);
    digitalWrite(IN_2, LOW);
  }

  // Map speedInput from -100 to 100 to motor speed range (MinSpeed to MaxSpeed)
  int motorSpeed = map(abs(speedInput), 0, 100, MinSpeed, MaxSpeed);
  analogWrite(ENA, motorSpeed);

  // Reset encoder count before starting the movement
  resetEncoder();

  // Assuming the encoder gives 11 pulses per revolution and we know the wheel circumference
  // Wheel circumference should be in centimeters
  float pulsesPerRevolution = 11.0;  // Adjust if necessary
  float wheelDiameterCM = 6.8;  // Example: wheel diameter of 6.8 cm (adjust based on your wheel size)
  float wheelCircumferenceCM = PI * wheelDiameterCM;  // Calculate wheel circumference in cm

  // Calculate the required number of pulses for the given distance in cm
  float pulsesRequired = (distanceCM / wheelCircumferenceCM) * pulsesPerRevolution;

  // Move the robot until the encoder count reaches the required distance
  while (abs(readEncoder()) < pulsesRequired) {
    // Continuously move the robot until the required distance is reached
    delay(10);  // Small delay for smooth operation
  }

  // Stop the motors after reaching the distance
  StopMotors();
}

// Existing motor control function
void controlRobot(int speedInput, int steeringInput) {
  // Map speedInput from -100 to 100 to motor speed range
  int motorSpeed = map(abs(speedInput), 0, 100, MinSpeed, MaxSpeed);
  
  // Set motor direction based on the sign of speedInput
  if (speedInput > 0) {
    // Move forward
    digitalWrite(IN_1, HIGH);
    digitalWrite(IN_2, LOW);
  } else if (speedInput < 0) {
    // Move backward
    digitalWrite(IN_1, LOW);
    digitalWrite(IN_2, HIGH);
  } else {
    // Stop motors
    StopMotors();
  }

  // Set motor speed
  analogWrite(ENA, motorSpeed);

  // Map steeringInput from -100 to 100 to servo angle range (130 to 50 degrees)
  steeringAngle = map(steeringInput, -100, 100, 120, 60);

  // Set servo position
  STEERING.write(steeringAngle);
}

// Existing sensor functions
void setupSensors() {
  for (uint8_t i = 0; i < sensorCount; i++) {
    pinMode(xshutPins[i], OUTPUT);
    digitalWrite(xshutPins[i], LOW);
  }
  
  for (uint8_t i = 0; i < sensorCount; i++) {
    pinMode(xshutPins[i], INPUT);
    delay(10);

    sensors[i].setTimeout(500);
    if (!sensors[i].init()) {
      Serial.print("Failed to detect and initialize sensor ");
      Serial.println(i);
      while (1);  // Halt execution if sensor initialization fails
    }

    sensors[i].setAddress(0x2A + i);
    sensors[i].startContinuous(50);  // Start continuous measurement
  }
}

void readAndPrintDistances() {
  Serial.print("F: ");
  Serial.print(sensors[2].read());
  if (sensors[2].timeoutOccurred()) { Serial.print(" TIMEOUT"); }
  Serial.print("\t");

  Serial.print("R: ");
  Serial.print(sensors[3].read());
  if (sensors[3].timeoutOccurred()) { Serial.print(" TIMEOUT"); }
  Serial.print("\t");

  Serial.print("L: ");
  Serial.print(sensors[1].read());
  if (sensors[1].timeoutOccurred()) { Serial.print(" TIMEOUT"); }
  Serial.print("\t");

  Serial.print("B: ");
  Serial.print(sensors[0].read());
  if (sensors[0].timeoutOccurred()) { Serial.print(" TIMEOUT"); }
  Serial.println();

  delay(50);  // Delay to match the sensor's continuous reading interval
}

void StopMotors() {
  digitalWrite(IN_1, LOW);
  digitalWrite(IN_2, LOW);
  analogWrite(ENA, 0);  // Stop motor by setting speed to 0
}

void HoldMotors() {
  digitalWrite(IN_1, HIGH);
  digitalWrite(IN_2, HIGH);
  analogWrite(ENA, 0);  // Stop motor by setting speed to 0
}

// Existing buzzer functions
void BuzzerRobotStart() {
  for (int i = 0; i < 3; i++) {
    tone(buzzerPin, 1000);  // Frequency of 1000 Hz
    delay(200);
    noTone(buzzerPin);
    delay(100);
  }
}

void BuzzerRobotEnd() {
  tone(buzzerPin, 500);  // Lower frequency for end sound
  delay(1000);           // Long beep for 1 second
  noTone(buzzerPin);
}

void BuzzerRobotError() {
  for (int i = 0; i < 5; i++) {
    tone(buzzerPin, 1500);  // Higher frequency for error
    delay(100);
    noTone(buzzerPin);
    delay(100);
  }
}

void BuzzerRobotSpecial() {
  int melody[] = { 262, 294, 330, 349 };  // Notes for C, D, E, F
  for (int i = 0; i < 4; i++) {
    tone(buzzerPin, melody[i]);
    delay(300);
    noTone(buzzerPin);
    delay(100);
  }
}

// Function to send data to Raspberry Pi
void sendDataToPi() {
  int frontDist = sensors[2].read();
  int rightDist = sensors[3].read();
  int leftDist = sensors[1].read();
  int backDist = sensors[0].read();
  int gyroZ = analogRead(A2);  // Example reading for gyroscope z-axis (replace if using actual sensor)
  float encoderSpeed = motorSpeedRPM;

  // Send data as a comma-separated string
  Serial.print(frontDist); Serial.print(",");
  Serial.print(rightDist); Serial.print(",");
  Serial.print(leftDist); Serial.print(",");
  Serial.print(backDist); Serial.print(",");
  Serial.print(gyroZ); Serial.print(",");
  Serial.println(encoderSpeed);
}

// Function to receive and parse control data from Raspberry Pi
void receiveDataFromPi() {
  if (Serial.available() > 0) {
    String receivedData = Serial.readStringUntil('\n');  // Read incoming data until newline character
    int delimiterIndex = receivedData.indexOf(',');      // Find comma separator

    if (delimiterIndex > 0) {
      // Parse speedInput and steeringInput from the received data
      int speedInput = receivedData.substring(0, delimiterIndex).toInt();
      int steeringInput = receivedData.substring(delimiterIndex + 1).toInt();

      // Call control function with received inputs
      controlRobot(speedInput, steeringInput);
    }
  }
}

bool isSwitchOn(int value) {
  return value > 1000;  // Return true if analog reading is close to 1023 (switch on)
}

void act(){
  sendDataToPi();       // Send sensor and motor data to Raspberry Pi
  receiveDataFromPi();  // Receive control data from Raspberry Pi
  }

// Setup function
void setup() {
  Serial.begin(115200);
  Wire.begin();
  Wire.setClock(400000);  // Set I2C clock speed

  // Initialize motor and buzzer pins
  pinMode(ENA, OUTPUT);
  pinMode(IN_1, OUTPUT);
  pinMode(IN_2, OUTPUT);
  pinMode(buzzerPin, OUTPUT);
  
  pinMode(buzzerPin, OUTPUT);  // Set buzzer pin as output

  STEERING.attach(STEERING_SERVO_PIN);   // Initialize Steering Servo

  StopMotors();  // Ensure motors are stopped initially

  setupSensors();  // Initialize sensors
  setupEncoder();  // Initialize encoder

  BuzzerRobotStart();  // Play the start sound

}

// Loop function
void loop() {
  int switchValue = analogRead(switchPin); // Read the analog value of the switch

  if (isSwitchOn(switchValue)) { // Check if switch is on
    act();
  } else {
    HoldMotors();
    BuzzerRobotError();
  }
}

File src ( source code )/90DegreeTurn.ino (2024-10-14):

#include <Servo.h>          // Include the Servo library
#include <Wire.h>           // Include Wire library for I2C communication
#include <MPU6050.h>        // Include MPU6050 library

// ---------------------------
// Motor Control Definitions
// ---------------------------
#define ENA  11             // L298N EN_A motor speed control
#define IN_1  13            // L298N IN1 for motor direction
#define IN_2  12            // L298N IN2 for motor direction

// ---------------------------
// Servo Control Definitions
// ---------------------------
#define STEERING_SERVO_PIN 10  // Servo control pin

Servo STEERING;             // Create Servo object

// ---------------------------
// MPU6050 Definitions
// ---------------------------
MPU6050 mpu;

// Variables to store raw gyro readings
int16_t rawGyroZ;

// Variables to store converted gyro readings in degrees per second
float gyroZ;

// Calibration offsets
float gyroOffsetZ = 0.0;

// Gyroscope scale factor based on full-scale range (±250°/s)
const float GYRO_SCALE = 250.0 / 32768.0;

// Threshold to determine significant rotation (adjust as needed)
const float ROTATION_THRESHOLD = 10.0; // in degrees per second

// Accumulated rotation
float accumulatedRotationZ = 0.0;

// ---------------------------
// Speed and Steering Parameters
// ---------------------------
const int MaxSpeed = 255;
const int MinSpeed = 0;
int steeringAngle = 0;

// ---------------------------
// Timing Definitions
// ---------------------------
unsigned long previousTime = 0;

// ---------------------------
// Function Prototypes
// ---------------------------
void controlRobot(int speedInput, int steeringInput);
void StopMotors();
bool initializeMPU6050();
void calibrateGyroscope();
void turn90Degrees();

// ---------------------------
// Robot Control Function
// ---------------------------
void robotControl() {
  // Example behavior: Move forward for 2 seconds, turn 90 degrees, repeat
  
  // Move forward
  controlRobot(100, 0);  // 50% speed, neutral steering
  delay(1000);          // Move forward for 2 seconds
  
  // Turn 90 degrees to the right
  turn90Degrees();
  
  // Move forward again
  controlRobot(100, 0);  // 50% speed, neutral steering
  delay(1000);          // Move forward for 2 seconds
  
  // Turn 90 degrees to the right
  turn90Degrees();
  
  // Stop after completing actions
  StopMotors();
  delay(1000);          // Wait for 2 seconds before repeating
}

// ---------------------------
// Control Robot Function
// ---------------------------
void controlRobot(int speedInput, int steeringInput) {
  // Map speedInput from -100 to 100 to motor speed range 0 to MaxSpeed
  int motorSpeed = map(abs(speedInput), 0, 100, MinSpeed, MaxSpeed);
  
  // Set motor direction based on the sign of speedInput
  if (speedInput > 0) {
    // Move forward
    digitalWrite(IN_1, HIGH);
    digitalWrite(IN_2, LOW);
  } else if (speedInput < 0) {
    // Move backward
    digitalWrite(IN_1, LOW);
    digitalWrite(IN_2, HIGH);
  } else {
    // Stop motors
    digitalWrite(IN_1, LOW);
    digitalWrite(IN_2, LOW);
  }

  // Set motor speed
  analogWrite(ENA, motorSpeed);

  // Map steeringInput from -100 to 100 to servo angle range 130 to 50 degrees
  steeringAngle = map(steeringInput, -100, 100, 130, 50);

  // Set servo position
  STEERING.write(steeringAngle);
}

// ---------------------------
// Stop Motors Function
// ---------------------------
void StopMotors() {
  digitalWrite(IN_1, LOW);
  digitalWrite(IN_2, LOW);
  analogWrite(ENA, 0);
  STEERING.write(90); // Center steering
}

// ---------------------------
// Initialize MPU6050 Function
// ---------------------------
bool initializeMPU6050() {
  Wire.begin();
  mpu.initialize();
  
  // Check connection
  if (!mpu.testConnection()) {
    return false;
  }
  
  // Configure the gyro sensitivity (±250°/s)
  mpu.setFullScaleGyroRange(MPU6050_GYRO_FS_250);
  
  return true;
}

// ---------------------------
// Calibrate Gyroscope Function
// ---------------------------
void calibrateGyroscope() {
  Serial.println("Calibrating gyroscope. Please keep the robot stationary.");
  int numSamples = 100;
  long sumZ = 0;
  
  for (int i = 0; i < numSamples; i++) {
    rawGyroZ = mpu.getRotationZ(); // Corrected function call
    sumZ += rawGyroZ;
    delay(10); // Adjust delay based on desired sample rate
  }
  
  gyroOffsetZ = ((float)sumZ / numSamples) * GYRO_SCALE;
  
  Serial.println("Gyroscope calibration complete.");
  Serial.print("Gyro Offset Z: "); Serial.print(gyroOffsetZ, 2); Serial.println(" °/s");
}

// ---------------------------
// Turn 90 Degrees Function
// ---------------------------
void turn90Degrees() {
    Serial.println("Initiating 90-degree turn...");

    // Reset accumulated rotation
    accumulatedRotationZ = 0.0;

    // Set previous time for delta time calculation
    previousTime = millis();

    // Start turning to the right at a higher speed
    int turnSpeed = 200;  // Set a constant high speed (80% or more)
    controlRobot(turnSpeed, 100);  // High speed, full steering to the right

    while (abs(accumulatedRotationZ) < 90.0) {
        // Read gyro data
        rawGyroZ = mpu.getRotationZ();
        gyroZ = ((float)rawGyroZ) * GYRO_SCALE - gyroOffsetZ;

        // Get current time
        unsigned long currentTime = millis();

        // Calculate delta time in seconds
        float deltaTime = (currentTime - previousTime) / 1000.0;
        previousTime = currentTime;

        // Calculate angle change
        float angleChange = gyroZ * deltaTime;

        // Accumulate rotation
        accumulatedRotationZ += angleChange;

        // Debugging output
        Serial.print("Gyro Z: "); Serial.print(gyroZ, 2); Serial.print(" °/s\t");
        Serial.print("Accumulated Rotation Z: "); Serial.print(accumulatedRotationZ, 2); Serial.println(" °");

        delay(10); // Small delay to prevent excessive serial output
    }

    // Stop turning
    StopMotors();
    Serial.println("90-degree turn complete!");

    delay(1000); // Brief pause after turning
}

// ---------------------------
// Setup Function
// ---------------------------
void setup() {
  // Initialize Serial Communication
  Serial.begin(115200);
  while (!Serial) { ; } // Wait for Serial to be ready

  // Initialize Motor Control Pins
  pinMode(ENA, OUTPUT);
  pinMode(IN_1, OUTPUT);
  pinMode(IN_2, OUTPUT);
  
  // Initialize Steering Servo
  STEERING.attach(STEERING_SERVO_PIN);
  
  // Initialize motors to stopped state
  StopMotors();
  
  // Initialize MPU6050
  if (!initializeMPU6050()) {
    Serial.println("Failed to initialize MPU6050. Check connections.");
    while (1); // Halt if initialization fails
  }
  
  // Calibrate Gyroscope
  calibrateGyroscope();
  Serial.println("Calibration complete. Starting operation.");
}

// ---------------------------
// Loop Function
// ---------------------------
void loop() {
  // Call the main robot control function
  robotControl();
}

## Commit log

2024-08-01 Rename 38486-LC.step to AUVIDEA JN30D for NVIDIA jetson Nano Datasheet.step
    [AUVIDEA JN30D for NVIDIA jetson Nano Datasheet.step]
2024-09-05 Create 0x00-VL53L1X DTOF Sensor
2024-09-05 Rename other/component Details/0x00-VL53L1X DTOF Sensor/test to other/component Details/0x00-VL53L1X DTOF Sensor/3D Models/test
2024-10-08 Create version 1 (first prototype)
2024-10-09 Rename Screenshot 2024-09-21 203823.png to DTOF sensor.png
2024-10-09 Rename Screenshot 2024-09-21 162700.png to Steering.png
2024-10-09 Rename WhatsApp Image 2024-09-21 at 20.10.13.jpeg to Power System.png
2024-10-09 Rename Screenshot 2024-10-09 194248.png to Power System.png
2024-10-15 Rename A000005-datasheet.pdf to Arduino NANO Datasheet.pdf
2024-10-18 Rename other/Power System/Power System.png to images/Power System.png
2024-10-18 Rename other/Sensing Units/DTOF sensor.png to images/DTOF sensor.png
2024-10-18 Rename other/Steering System/Steering.png to images/Steering.png
2024-10-18 Rename BATTERY (2).png to livo battery level sensor.png
2024-10-19 Rename src ( source code )/Test/BuzzerSerialCommunication.py to src ( source code )/Test/Buzzer/BuzzerSerialCommunication.py
    [BuzzerSerialCommunication.py]
2024-10-23 Rename Rpf-raspberry-pi-4-model-b-removebg-preview.png to Raspberry pi 4B
2024-10-23 Rename Raspberry pi 4B to Raspberry pi 4B.png
2024-10-23 Create 0x05Front Short Shaft
2024-10-23 Rename Robot Base (2).stl to Robot Base .stl
    [Robot Base .stl]
2024-10-23 Rename Second Layer (2).stl to Second Layer .stl
    [Second Layer (2).stl, Second Layer .stl]
2024-10-23 Rename Second Layer (1).stl to Second Layer .stl
    [Second Layer (1).stl, Second Layer .stl]
2024-10-23 Update and rename Second Layer .stl to Second Layer(1) .stl
    [Second Layer(1) .stl]
2024-10-25 Rename Models/ Parts/0x13-Front Carries Camera/README.md to Models/ Parts/0x13-Front Support CameraREADME.md
2024-10-25 Rename Models/ Parts/0x13-Front Support CameraREADME.md to Models/ Parts/0x13-Front Support Camera/README.md
2024-10-25 Rename Isometric Short Shaft.png to 0x03-Isometric Short Shaft.png
2024-10-25 Rename Isometric Long Short Shaft.png to 0x04-Isometric Long Short Shaft.png
2024-10-25 Rename Isometric Front Short Shaft.png to 0x05-Isometric Front Short Shaft.png
2024-10-25 Rename Isometric Axle Calamp.png to 0x06-Isometric Axle Calamp.png
2024-10-25 Rename Isometric Steering Rack.png to 0x09-Isometric Steering Rack.png
2024-10-25 Rename Isometric Steering Conector.png to 0x10-Isometric Steering Conector.png
2024-10-25 Rename Isometric Gear.png to 0x11-Isometric Gear.png
2024-10-25 Rename Isometric Big Gear.png to 0x12-Isometric Big Gear.png
2024-10-25 Rename Isometric Front Support Camera.png to 0x13-Isometric Front Support Camera.png
2024-10-25 Rename Isometric Back Support Camera.png to 0x14-Isometric Back Support Camera.png
2024-10-25 Rename Isometric Conector Support Camera.png to 0x15-Isometric Conector Support Camera.png
2024-10-26 Rename Long Short Shaft.stl to Long Shaft.stl
    [Long Shaft.stl]
2024-10-27 Rename 0x04-Isometric Long Short Shaft.png to 0x04-Isometric Long Shaft.png
2024-10-27 Rename 0x06-Isometric Axle Calamp.png to 0x09-Isometric Axle Calamp.png
2024-10-27 Rename 0x09-Isometric Steering Rack.png to 0x08-Isometric Steering Rack.png
2024-10-27 Rename 0x09-Isometric Axle Calamp.png to 0x10-Isometric Axle Calamp.png
2024-10-27 Rename 0x10-Isometric Steering Conector.png to 0x09-Isometric Steering Conector.png
2024-10-27 Rename 0x11-Isometric Gear.png to 0x12-Isometric Gear.png
2024-10-27 Rename 0x12-Isometric Big Gear.png to 0x11-Isometric Big Gear.png
2024-10-27 Rename 0x10-Isometric Axle Calamp.png to 0x10-Isometric Axle Clamp.png
2024-10-29 Rename Screenshot 2024-10-29 203121.png to Onshape robot CAD.png
2024-10-31 Rename 0x10-Isometric Steering Conector.png to 0x10-Isometric Steering Connector.png
2024-10-31 Rename 0x15-Isometric Conector Support Camera.png to 0x15-Isometric Connector Support Camera.png
2024-10-31 Rename 0x08-Isometric Berring Support Front Top.png to 0x08-Isometric Bearing Support Front Top.png
2024-10-31 Rename 0x07-Isometric Berring Support Front Bottom.png to 0x07-Isometric Bearing Support Front Bottom.png
2024-10-31 Rename src ( source code )/Fonction.ino to src ( source code )/Arduino Functions/Fonction.ino
2024-11-03 Rename Screenshot 2024-11-03 160238.png to Robot Circuit.png
2024-11-04 Rename 0x08-Isometric Bearing Support Front Top.png to 0x07-Isometric Bearing Support Front Top.png
2024-11-04 Rename 0x07-Isometric Bearing Support Front Bottom.png to 0x06-Isometric Bearing Support Front Bottom.png
2024-11-04 Rename 0x06-Isometric Axle Clamp.png to 0x10-Isometric Axle Clamp.png
2024-11-04 Rename 0x10-Isometric Steering Connector.png to 0x09-Isometric Steering Connector.png
